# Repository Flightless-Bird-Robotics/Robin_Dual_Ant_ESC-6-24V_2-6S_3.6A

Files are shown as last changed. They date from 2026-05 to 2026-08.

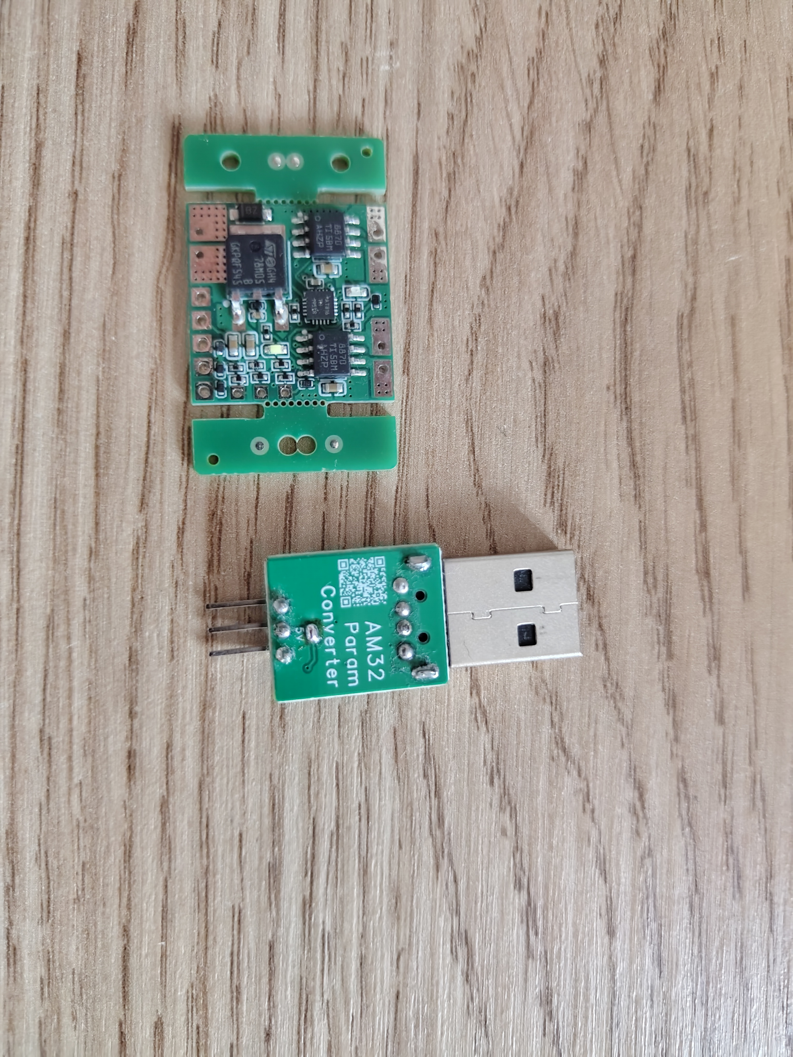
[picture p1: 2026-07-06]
ReadmeMedia/Dual_ESC_6-24V_3.6A_V4_Flash_AM32_3.jpg.jpg

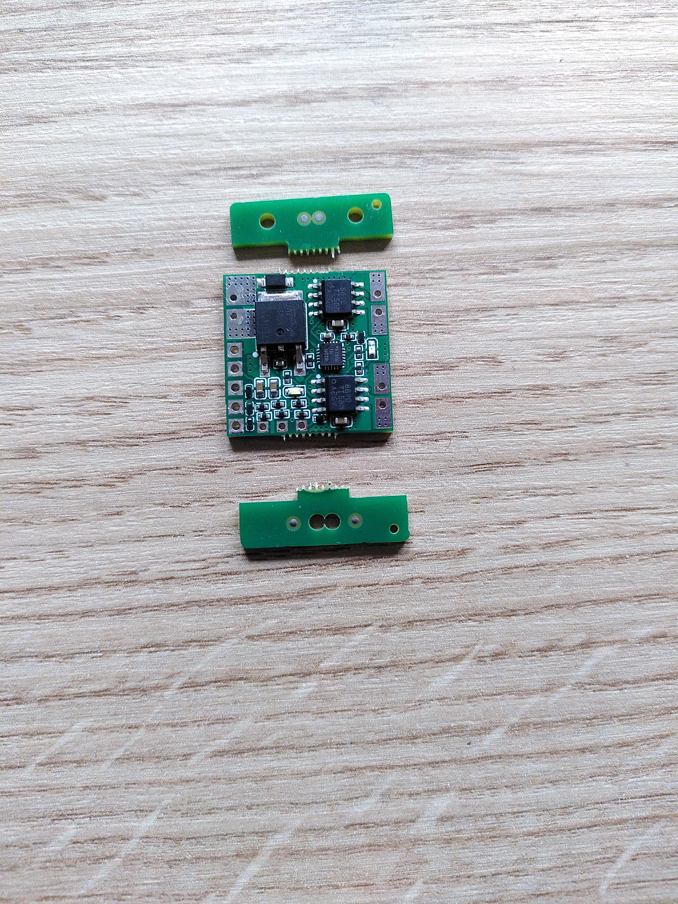
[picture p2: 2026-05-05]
ReadmeMedia/ESC_without_panels.jpg

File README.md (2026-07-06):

# Robin_Dual_Ant_ESC-6-24V_2-6S_3.6A
This ESC is designed for 150g Ant weight combat robots to drive N20 and N10 brushed motors.
It takes standard RC PWM signals as inputs and supports internal mixing and overhead driving.
The ESC is designed to be used with 2-6S, and a maximum current of 3.6A per channel.
The ESC has internal current limiting and thermal shutdown.
The internal BEC can supply up to 100mA for a receiver. An external BEC should be used for voltages over 4S(16.8V).
The PCB without the panels is 22x22mm and weighs 2.3g.

## Wiring section
Dual_ESC_6-24V_3 6A_V3_Wiring_V2
The panels at the top and bottom are just for manufacturing and can be snapped off to reduce the overall size and weight.
ESC_without_panels
The 3 pins at the bottom are for flashing the MCU and are not used in normal operation.
I recomnend to connect the motor 1 to the left drive motor and motor 2 to the right drive motor. The motor 2 polarity should be reversed. This makes mixing later on much easier, and ensures that overhead driving will work correctly. 
You can use standart 2.54mm pitch pins (2x for the battery and motors and 5x for the signal, 5V and GND) to connect the ESC. 
Dual_ESC_6-24V_3 6A_V4_With_Pins
Otherwide you can directly solder it. 

## Programming section
On startup the red LED wil blink once, and the ESC will beep once plus once every cell found when UVLO is enabled.
To program the ESC, power it on and wait for the red LED blink a second time.
The ESC is now in programming mode. 
Any non zero input on the Signal 1 and Signal 2 will end the programming mode. The red LED will be permanently on when in driving mode. 
To enter prgramming mode again, the ESC needs to be power cycled.
In programming mode changing the signal 3 to high (>80) increases the programming counter and the red led blinkes once.
If the right menu number is reached, wait for the red led to blink without any input. The setting has now been activated/deactivated.

| Number  | Function | Default |
| --- | --- | --- |
| 1  | None  |  |
| 2  | No mixing | No mixing |
| 3  | 25% mixing | No mixing |
| 4  | 50% mixing | No mixing |
| 5  | 75% mixing | No mixing |
| 6  | 100% mixing | No mixing |
| 7  | Breaking on/off | Breaking on |
| 8  | Invert channel 1 | Not inverted |
| 9  | Invert channel 2 | Not inverted |
| 10  | Switch channel 1 & 2 | Not switched |
| 11  | Under voltage lockout at 3V per cell  | UVLO off |
| 12  | Wider deadzone on/off | off |
| 13  | reset to default |  |

The UVLO only works when the ESC is connected to a full Lipo on startup, otherwise the ESC cannot detect the number of cells.
On startup the ESC will beep once plus once every cell found.
The motor drivers shut off at 6V, even without UVLO enabled.

## Mixing section
How to set up the ESC for internal mixing with signal 1 for steering and signal 2 for forwards/reverse.
1. Check if motor 1 is the right side drive motor, and the motor is connected with normal polarity.
2. Check if motor 2 is the left side drive motor, and the motor is connected with reversed polarity.
3. Chose on of the 4 mix settings. I recommend to try out every one to get the steering level you are most comfortable with.

## Manufacturing section
### Manufacturing with EasyEDA and JLCPCB
The ESC is designed to be cheaply manufactured in batches as small as 5. (The lowest quantity JLC will manufacture)
The last batch of 5 from JLC cost 22€ including shipping.

The easiest way to get your own ESC manufactured is by importing the .epro file to EasyEDA as a professional projekt.
You can find the file under Hardware/Version/... Now select import document and Library.
Now you need Open the PCB and press order/Order PCB and it will automatically import all the necessary data. Before ordering it will do a design rule check. It should not return any errors and you can continue with the order after it. 
You don't need to change any settings this way except selecting PCB Assembly. You can change the color, or to lead free finish on the PCB if you want, this does not impact the function at all.
Now you can continue to the folliwing steps without needing to change anything and finish your order. Don't forget to appy coupons JLC gives out at checkout.

If you want to order larger quanteties, you can pannelize the PCB in easyEDA under Tools/Panelize. This can be cheaper compared to just ordering a larger number of PCBs. You need to chose "Panel by Customer" when ordering if you do that.

### Manufacturing with gerber files
The other way to get your own PCB manufactured is to upload the Gerber, BOM and CPL file to a manufacturer of choice.
You can find the files under Hardware/Version/...
If you do it with JLC you might need to realign the components. For Other PCB manufacturers everything should work the same, but this was not tested.

### Substituting components for manufacturing
All resistors, TVS Diodes and capacitors are generic. They can be replaced with same spec ones if necessary.
There are generics of the DRV8870 which should work the same, but those were not tested.
The Attiny816 can be replaced with an Attiny1616 if the 816 is not available for whatever reason.
The LDO can be replaced with a same spec LDO if necessary too.

## Flashing section
The microcontroller is flashed using the Arduino IDE and MegaTinyCore from Spencer Konde https://github.com/SpenceKonde/megaTinyCore
To flash the microcontroller a USB to serial adapter is necessary. I used one based on a CP2102M and a schottky diode between RX and TX.
It seems AM32 programmers works as well. I haven't tested this except with the one on the photo. The S pin goes on the UDPI pad.
If you want to try, I recommend to get one where you can deliver 5V to the pins, so you don't need an extra voltage source for programming.
Details to make your own can be found here https://github.com/SpenceKonde/AVR-Guidance/blob/master/UPDI/jtag2updi.md
Once you have installed the MegaTinyCore into the Arduino IDE you need to set the upload settings
Arduino Settings
Now you can connect the UDPI, 5V and GND from the serial adapter to the 3 pins at the bottom.
Dual_ESC_6-24V_3 6A_V3_Flash_Wiring_V2
MCU_Flashing_Photo
Dual_ESC_6-24V_3 6A_V4_Flash_AM32_1
Dual_ESC_6-24V_3 6A_V4_Flash_AM32_3 jpg
Dual_ESC_6-24V_3 6A_V4_Flash_AM32_2 jpg
Now select "Burn bootloader" at the bottom of the "Tools" menue. 
Now you can press upload in the Arduino IDE to upload the code. 
You can check if the microcontroller was flashed sucsecfully by the red led blinking, indicating the programming mode. The ESC can now be used.

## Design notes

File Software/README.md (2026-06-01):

# Software
The software for the ESC is placed here
To uploade it to the ESC you need the Arduino IDE and MegaTinyCore https://github.com/SpenceKonde/megaTinyCore
and a Serial to USB Adapter with an added schottkey diode https://github.com/SpenceKonde/AVR-Guidance/blob/master/UPDI/jtag2updi.md

## The current version is V4
The older version should not be used for harware version 4 and upwards

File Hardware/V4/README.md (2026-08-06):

## Version 4 
This is the fourth hardware version of the dual ant esc
Changes:  -Changed the pinout of the Attiny816 to enagle UVLO
          -Changed the input TVS diode to unidirectional to better protect the input
          -small changes to the silkscreen
          -chnaged some conections for better thermal performance

Added a EasyEDA .epro2 file.
This file is for the version V3 of EasyEDA and should be used for imports in to EasyEDA.

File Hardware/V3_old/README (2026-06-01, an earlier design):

## The UVLO is without function on this Hardware
This is the third hardware version of the dual ant esc
Changes:  -Changed the programing pads to multilayer to make it easier to program with a serial adapter
          -Added through holes to the VIN, GND and motor pads, to give the option to add 2.54mm pitch throughole pins
          -Changed the 5V TVS diodes to unidirectional to better protect the MCU
          -Added pulldown and series resistors on the signal pins to prevent undefined states on the MCU and better protect the MCU
          -Added series Resistor on the UDPI pin to better protect the MCU

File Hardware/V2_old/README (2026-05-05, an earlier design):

**The UVLO is without function on this Hardware**
**This version has multible problems and should not be used.**

This is the second hardware version of this projekt
Changes:  -Cheaper, slightly larger motor drivers were used
          -The pcb size was increased slightly from 20x20mm to 22x22mm

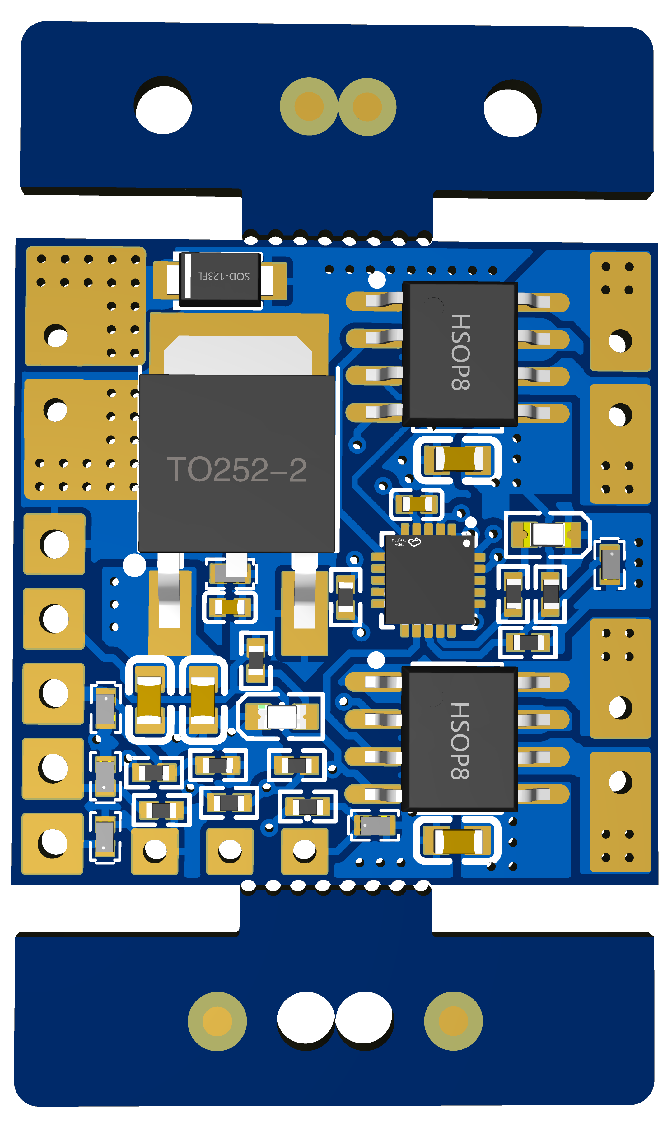
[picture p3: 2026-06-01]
Hardware/V4/Dual_ESC_6-24V_3.6A_V4_Top.png

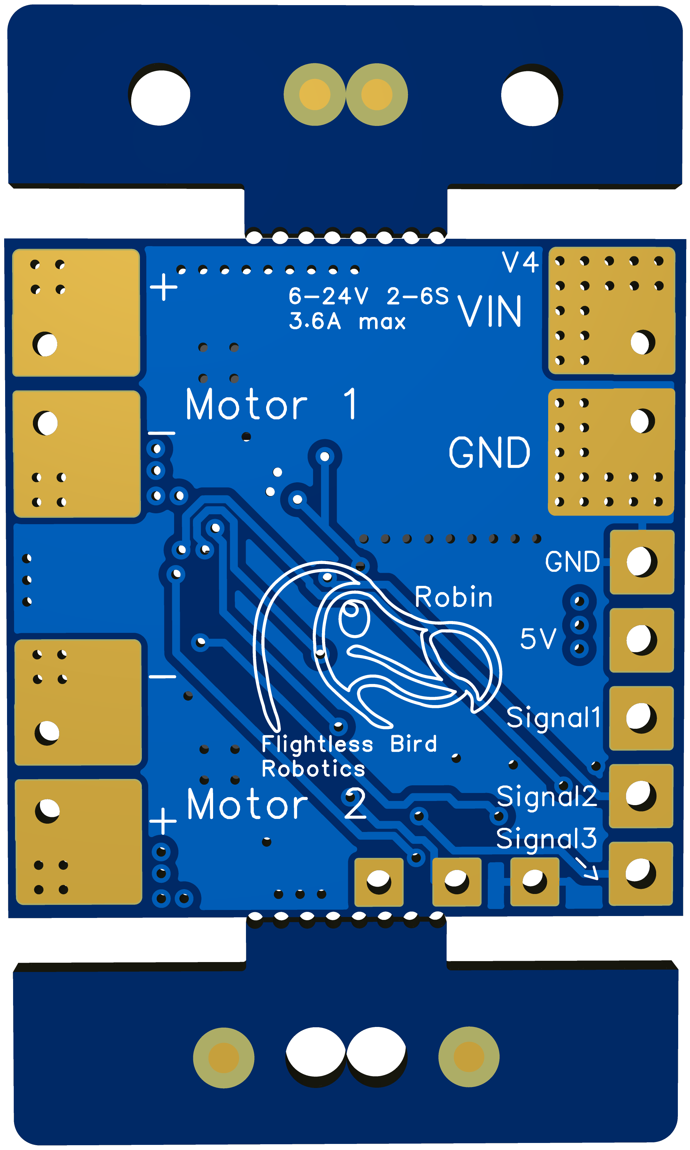
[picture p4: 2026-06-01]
Hardware/V4/Dual_ESC_6-24V_3.6A_V4_Bottom.png

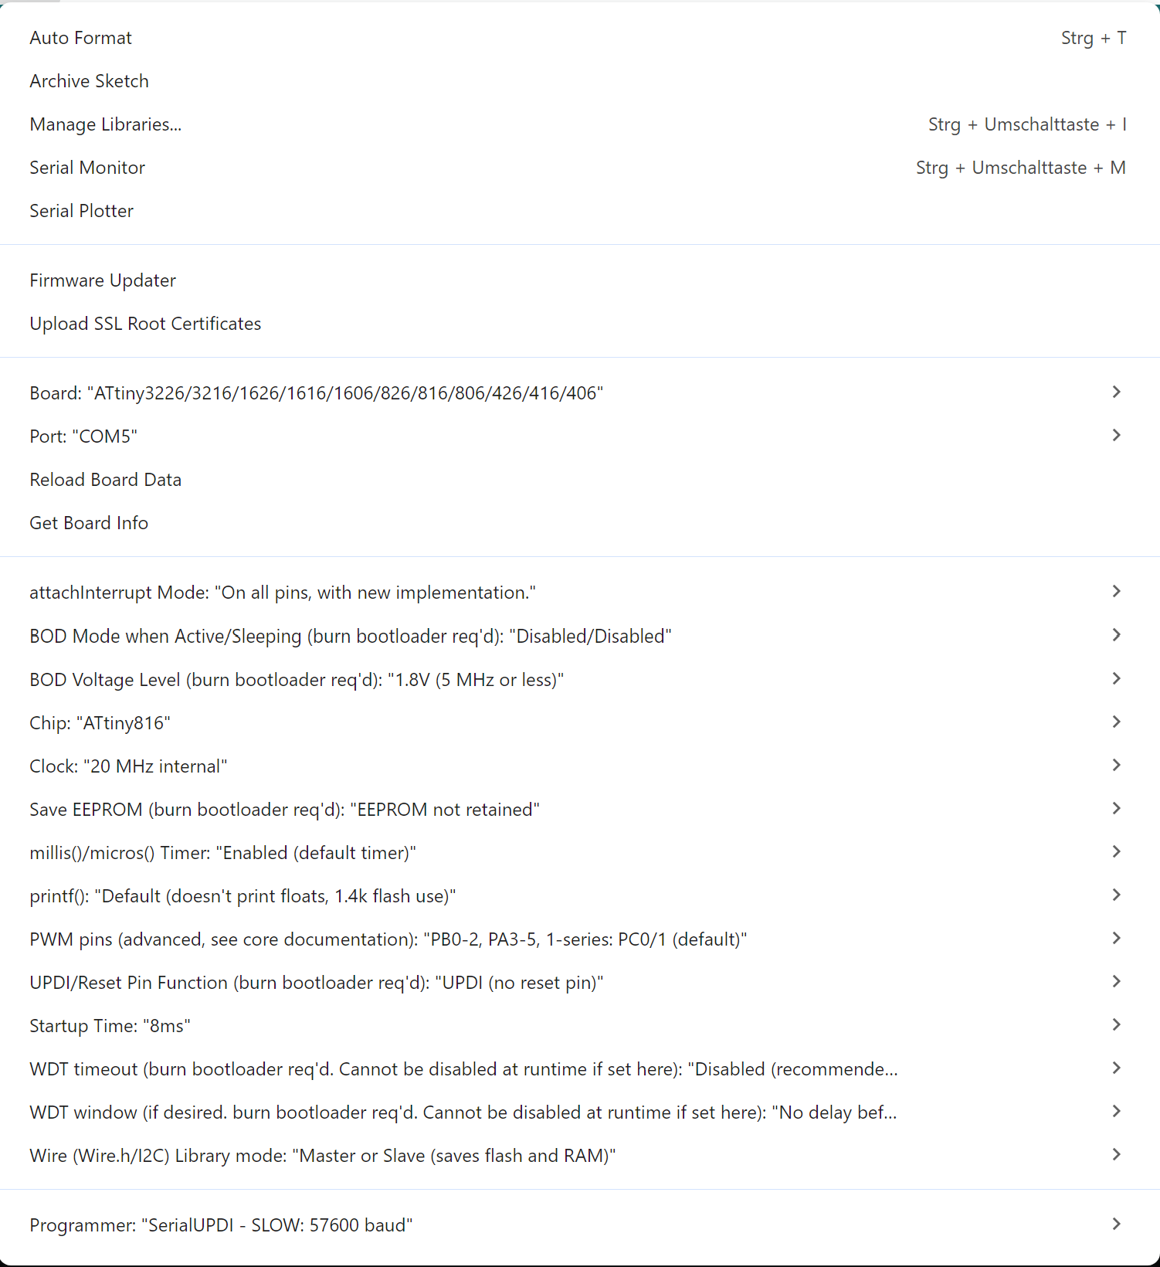
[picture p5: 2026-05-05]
ReadmeMedia/Arduino Settings.png

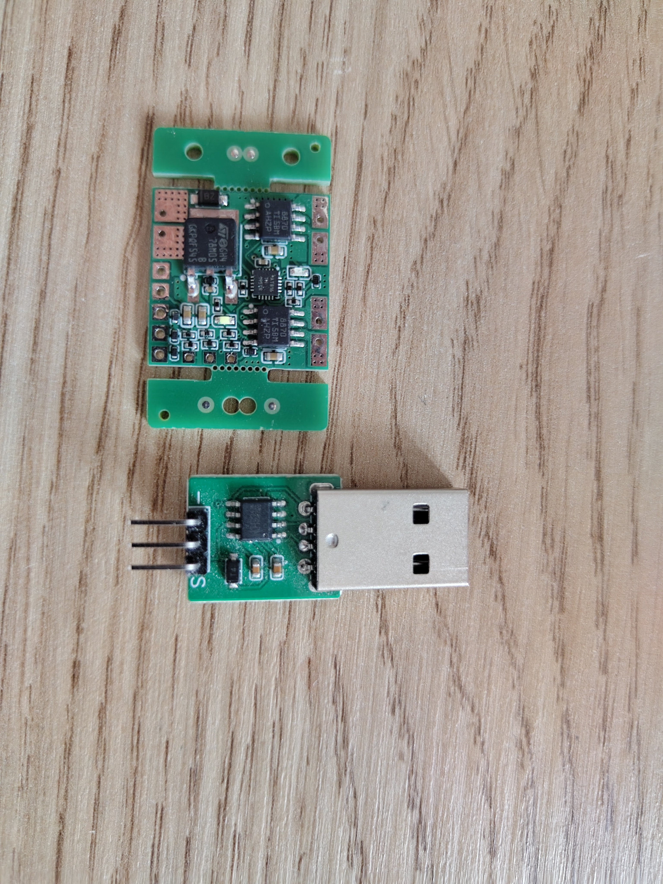
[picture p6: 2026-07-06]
ReadmeMedia/Dual_ESC_6-24V_3.6A_V4_Flash_AM32_2.jpg.jpg

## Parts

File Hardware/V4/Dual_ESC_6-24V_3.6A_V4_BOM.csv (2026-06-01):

No. | Quantity | Comment | Designator | Footprint | Value | Manufacturer Part | Manufacturer | Supplier Part | Supplier
1 | 2 | 1uF | C1,C3 | C0402 | 1uF | CL05A105KA5NQNC | SAMSUNG(三星) | C52923 | LCSC
2 | 4 | 1uF | C2,C4,C5,C6 | C0603 | 1uF | CL10A105KB8NNNC | SAMSUNG(三星) | C15849 | LCSC
3 | 1 | SMF24A | D3 | SOD-123FL_L2.7-W1.8-LS3.8-RD |  | SMF24A | R+O(宏嘉诚) | C19077514 | LCSC
4 | 6 | H5VU10U | D4,D5,D6,D7,D8,D9 | DFN1006-2L-RD |  | H5VU10U | R+O(宏嘉诚) | C22395519 | LCSC
5 | 1 | KT-0603R | LED1RED | LED0603-RD |  | KT-0603R | KENTO | C2286 | LCSC
6 | 1 | KT-0603W | LED2YELLOW | LED0603-R-RD_WHITE |  | KT-0603W | KENTO | C2290 | LCSC
7 | 1 | 100kΩ | R1 | R0402 | 100kΩ | 0402WGF1003TCE | UNI-ROYAL(厚声) | C25741 | LCSC
8 | 4 | 10kΩ | R2,R9,R10,R11 | R0402 | 10kΩ | 0402WGF1002TCE | UNI-ROYAL(厚声) | C25744 | LCSC
9 | 2 | 510Ω | R3,R4 | R0402 | 510Ω | 0402WGF5100TCE | UNI-ROYAL(厚声) | C25123 | LCSC
10 | 4 | 100Ω | R5,R6,R7,R8 | R0402 | 100Ω | 0402WGF1000TCE | UNI-ROYAL(厚声) | C25076 | LCSC
11 | 1 | ATTINY816-MNR | U1 | UQFN-20_L3.0-W3.0-P0.40-BL-EP1.7 |  | ATTINY816-MNR | MICROCHIP(美国微芯) | C2052778 | LCSC
12 | 1 | L78M05ABDT-TR | U2 | TO-252-2_L6.5-W6.1-P4.58-LS10.0-TL |  | L78M05ABDT-TR | ST(意法半导体) | C58069 | LCSC
13 | 2 | DRV8870DDAR | U4,U5 | HSOP-8_L5.0-W4.0-P1.27-LS6.2-BL-EP |  | DRV8870DDAR | TI(德州仪器) | C86590 | LCSC

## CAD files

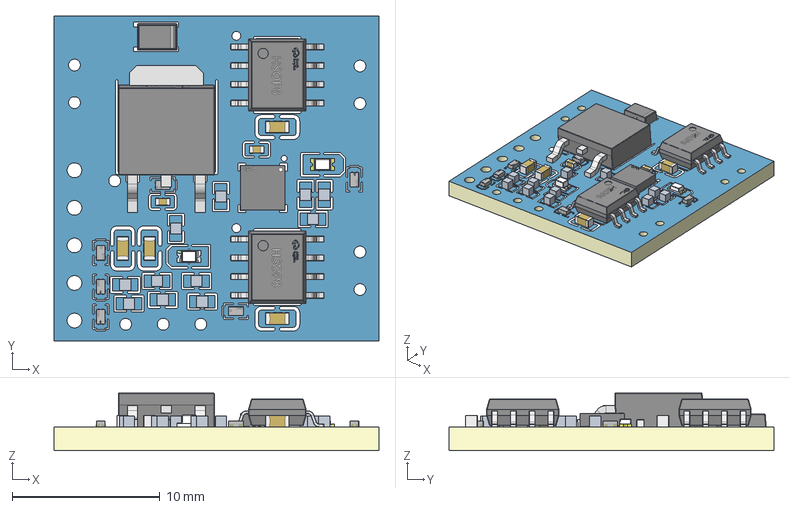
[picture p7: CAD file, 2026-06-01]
Hardware/V4/Dual_ESC_6-24V_3.6A_V4_3D.step
22.0 x 22.0 x 3.91 mm
Board~4Fxs
TopCopper~4Fxs
BottomCopper~4Fxs
TopSilkscreen~4Fxs
BottomSilkscreen~4Fxs
TopFpcStiffener~4Fxs
BottomFpcStiffener~4Fxs
C0402~C0402_L1.0-W0.5-H0.5~4Fxs x 2
R11~R0402~R0402_L1.0-W0.5-H0.4~4Fxs x 11
LED0603-RD~LED0603-RD~4Fxs
C0603~C0603_L1.6-W0.8-H0.8~4Fxs x 4
LED0603-R-RD_WHITE~LED0603-R-RD_WHITE~4Fxs
TO-252-2_L6.5-W6.1-P4.58-LS10.0-TL~TO-252-2_ L6.5-W6.1-H2.3-LS10.0-P4.58~4Fxs
SOD-123FL_L2.7-W1.8-LS3.8-RD~SOD-123FL_L2.8-W1.8-H1.1-LS3.6~4Fxs
UQFN-20_L3.0-W3.0-P0.40-BL-EP1.7~UQFN-20_L3.0-W3.0-P0.40-BL-EP1.7~4Fxs
DFN1006-2L-RD~DFN1006_L1-W0.6-H0.4-2L-RD~4Fxs x 6
HSOP-8_L5.0-W4.0-P1.27-LS6.2-BL-EP~HSOP-8_ L4.9-W3.9-H1.8-LS6.0-P1.27~4Fxs x 2

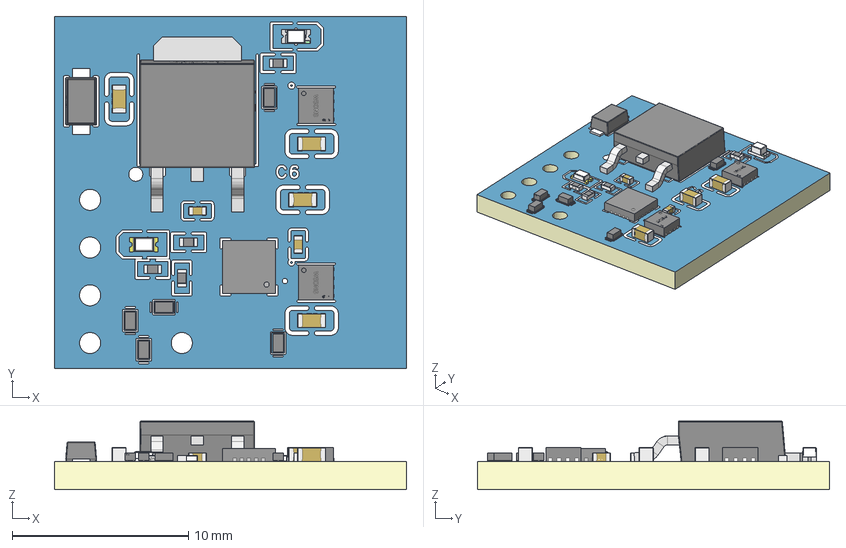
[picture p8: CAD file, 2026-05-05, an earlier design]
Hardware/V1_old/Dual_ESC_6-24V_3.7A_V1_3D.step
20.0 x 20.0 x 3.91 mm
Board~MFEQ
TopCopper~MFEQ
BottomCopper~MFEQ
TopSilkscreen~MFEQ
BottomSilkscreen~MFEQ
TopFpcStiffener~MFEQ
BottomFpcStiffener~MFEQ
C0603~C0603_L1.6-W0.8-H0.8~MFEQ x 4
C0402~C0402_L1.0-W0.5-H0.5~MFEQ x 2
LED0603-RD~LED0603-RD~MFEQ
TO-252-2_L6.5-W6.1-P4.58-LS10.0-TL~TO-252-2_ L6.5-W6.1-H2.3-LS10.0-P4.58~MFEQ
WSON-8_L2.0-W2.0-P0.50-TL-EP~WSON-8_L2.0-W2.0-H0.8-P0.50~MFEQ x 2
R0402~R0402_L1.0-W0.5-H0.4~MFEQ x 4
LED0603-R-RD_WHITE~LED0603-R-RD_WHITE~MFEQ
QFN-20_L3.0-W3.0-P0.40-BL-EP1.7~QFN-20_L3.0-W3.0-P0.40-BL-EP1.7~MFEQ
SOD-123FL_L2.7-W1.8-LS3.8-BI~SOD-123FL_L2.7-W1.8-LS3.8-BI~MFEQ
SOD-882_L1.0-W0.6-BI~WBFBP-03E_L1.0-W0.6-P0.64-BL~MFEQ x 5

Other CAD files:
Hardware/V2_old/Dual_ESC_6-24V_3.6A_V2_3D.step
Hardware/V3/Dual_ESC_6-24V_3.6A_V3_3D.step
Hardware/V3_old/Dual_ESC_6-24V_3.6A_V3_3D.step

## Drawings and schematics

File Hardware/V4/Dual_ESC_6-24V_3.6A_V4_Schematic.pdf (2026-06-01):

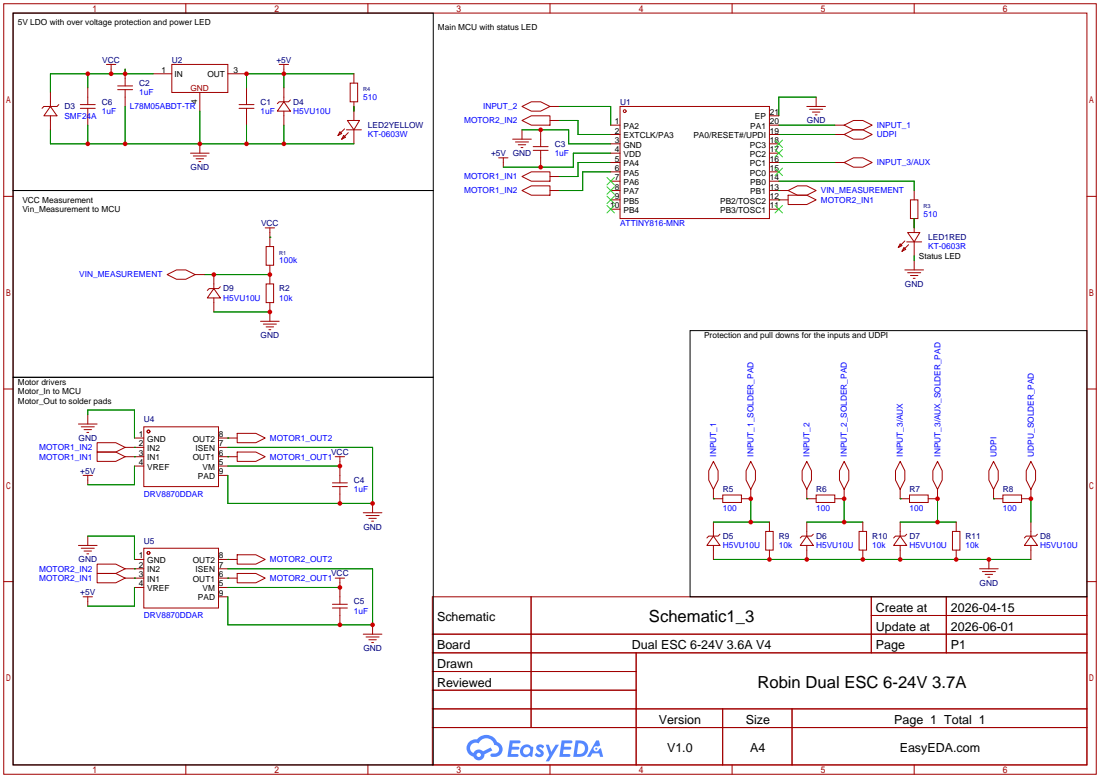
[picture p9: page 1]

5V LDO with over voltage protection and power LED

Main MCU with status LED

Protection and pull downs for the inputs and UDPI

Schematic | Schematic1_3 | Create at | 2026-04-15

Update at | 2026-06-01

Board | Dual ESC 6-24V 3.6A V4 | Page | P1
Drawn | | Robin Dual ESC 6-24V 3.7A
Reviewed

Version | Size | Page 1 Total 1
V1.0 | A4 | EasyEDA.com

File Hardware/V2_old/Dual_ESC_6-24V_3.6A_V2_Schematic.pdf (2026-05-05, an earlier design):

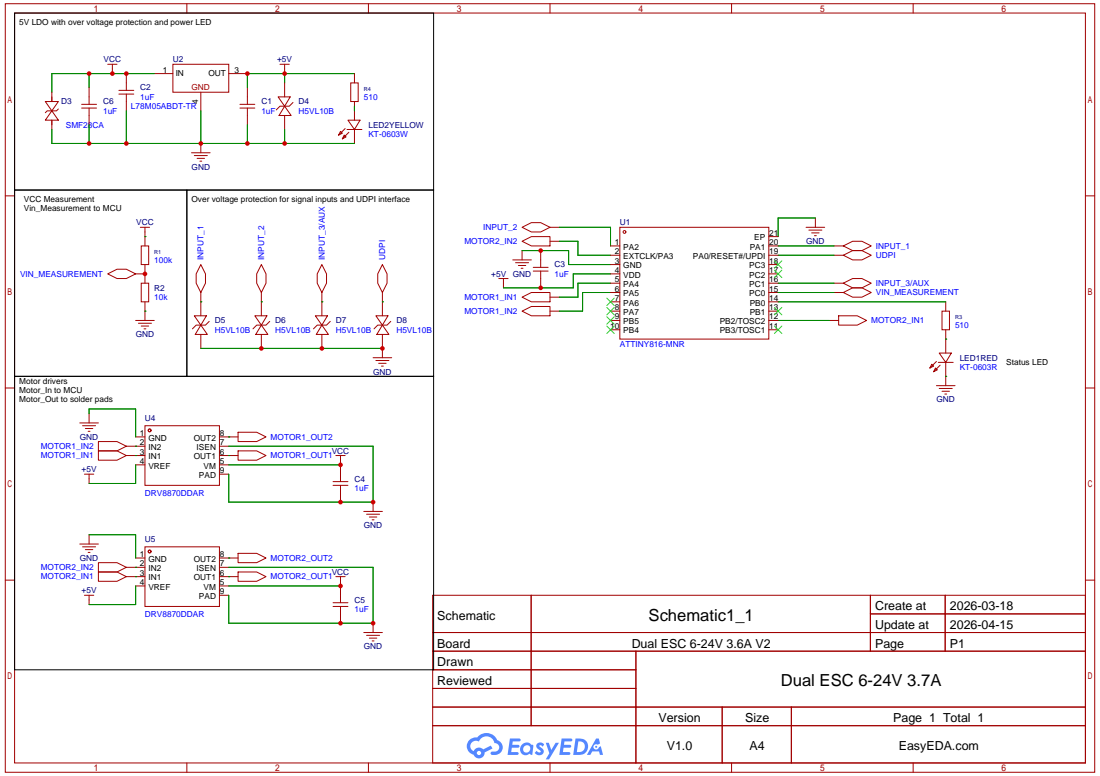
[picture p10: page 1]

5V LDO with over voltage protection and power LED

Over voltage protection for signal inputs and UDPI interface

Schematic | Schematic1_1 | Create at | 2026-03-18

Update at | 2026-04-15

Board | Dual ESC 6-24V 3.6A V2 | Page | P1
Drawn | | Dual ESC 6-24V 3.7A
Reviewed

Version | Size | Page 1 Total 1
V1.0 | A4 | EasyEDA.com

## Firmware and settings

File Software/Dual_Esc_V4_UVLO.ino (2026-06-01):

#include <EEPROM.h>

//Input pins
const int PIN_VIN = 8;

const int PIN_RC_THROTTLE = 14;
const int PIN_RC_STEERING = 15;
const int PIN_RC_AUX      = 11;

//Output pins
const int PIN_LED = 9;

const int PIN_MOTOR_L_A = 0;
const int PIN_MOTOR_L_B = 1;
const int PIN_MOTOR_R_A = 7;
const int PIN_MOTOR_R_B = 16;

const int MAX_PWM = 255;
const int SOUND_PWM_POWER = 60;

const float MIXING_LEVELS[] = {0.0, 0.25, 0.50, 0.75, 1.0};
float currentMix = 0.0;
int mixingIndex = 0;
const int EEPROM_ADDR_MIX = 0;
const int EEPROM_ADDR_BRAKE_EN = 1;
bool brakingEN = false;
const int EEPROM_ADDR_FLIP_CHANNEL_A_B = 2;
bool flipChannel = false;
const int EEPROM_ADDR_INVERT_A = 3;
bool invertA = false;
const int EEPROM_ADDR_INVERT_B = 4;
bool invertB = false;
const int EEPROM_ADDR_UVLO = 5;
bool UVLO = false;
const int EEPROM_ADDR_DEADZONE = 6;
int DEADZONE = 10;

bool inDrive = false;
bool lastAuxStateHigh = false;
bool auxStateChange = false;
bool setupMode = false;
int counter1 = 0;
int counter2 = 0;
int counter3 = 0;
int UVLOcells = 0;
int counterUVLO = 0;
int speedL = 0;
int speedR = 0;

// Variables for interrupts
volatile uint16_t tcb_start_steering = 0;
volatile uint16_t rc_steering_ticks = 0;
volatile uint16_t tcb_start_throttle = 0;
volatile uint16_t rc_throttle_ticks = 0;
volatile uint16_t tcb_start_aux = 0;
volatile uint16_t rc_aux_ticks = 0;
volatile uint16_t throttle_timer = 0;
volatile uint16_t steering_timer = 0;
volatile uint16_t aux_timer = 0;

void setup() {//start setup
  //enable WDT timers
  _PROTECTED_WRITE(WDT.CTRLA,WDT_PERIOD_1KCLK_gc);

//Initialize pins
  pinMode(PIN_MOTOR_L_A, OUTPUT); pinMode(PIN_MOTOR_L_B, OUTPUT);
  pinMode(PIN_MOTOR_R_A, OUTPUT); pinMode(PIN_MOTOR_R_B, OUTPUT);
  pinMode(PIN_RC_STEERING, INPUT); pinMode(PIN_RC_THROTTLE, INPUT); pinMode(PIN_RC_AUX, INPUT);
  pinMode(PIN_LED, OUTPUT);pinMode(PIN_VIN,INPUT);

//Stop motors 
  stopMotors();

//Flash LED
  digitalWrite(PIN_LED, HIGH);                                                                                      

//Reading eeprom settings
  mixingIndex = EEPROM.read(EEPROM_ADDR_MIX);
  if (mixingIndex > 4){mixingIndex = 0;}
  currentMix = MIXING_LEVELS[mixingIndex];
  brakingEN = EEPROM.read(EEPROM_ADDR_BRAKE_EN);
  if(EEPROM.read(EEPROM_ADDR_BRAKE_EN) > 4){brakingEN = 0;}
  flipChannel = EEPROM.read(EEPROM_ADDR_FLIP_CHANNEL_A_B);
  if(EEPROM.read(EEPROM_ADDR_FLIP_CHANNEL_A_B) > 4){flipChannel = 0;}
  invertA = EEPROM.read(EEPROM_ADDR_INVERT_A);
  if (EEPROM.read(EEPROM_ADDR_INVERT_A) > 4){invertA = 0;}
  invertB = EEPROM.read(EEPROM_ADDR_INVERT_B);
  if (EEPROM.read(EEPROM_ADDR_INVERT_B) > 4){invertB = 0;}
  UVLO = EEPROM.read(EEPROM_ADDR_UVLO);   
  if (EEPROM.read(EEPROM_ADDR_UVLO) > 4){UVLO = 0;}
  if (EEPROM.read(EEPROM_ADDR_DEADZONE == 0)){
      DEADZONE = 40;
  }
  else {DEADZONE = 10;}

//Set the ADC voltage reference to 2.5V
  analogReference(2);
  delay(100);
//Set the ADC to 200kHz
  analogClockSpeed(200);
//Reading startup voltages for UVLO with 8 bit resolution and setting the detected number of cells/turning UVLO off
  if(analogReadEnh(PIN_VIN,8) >=  74  && analogReadEnh(PIN_VIN,8) <= 80){//8-8.6V                                        
    UVLOcells = 2;
  }
  else if(analogReadEnh(PIN_VIN,8) >= 111 && analogReadEnh(PIN_VIN,8) <= 120){//12-12.9V
    UVLOcells = 3;
  }
  else if (analogReadEnh(PIN_VIN,8) >= 148 && analogReadEnh(PIN_VIN,8) <= 160){//16-17.2V
    UVLOcells = 4;
  }
  else if (analogReadEnh(PIN_VIN,8) >= 185 && analogReadEnh(PIN_VIN,8) <= 200){//20-21.5V
    UVLOcells = 5;
  }
  else if (analogReadEnh(PIN_VIN,8) >= 222 && analogReadEnh(PIN_VIN,8) <= 240){//24-25.9V
    UVLOcells = 6;
  }
  else{
    UVLO = 0;
  }

       
  //Indicating the UVLO level   
  if (UVLO){                                                                  
    indicateMode(UVLOcells + 1);
  }
  else{
    indicateMode(1);
  }

//Setting registers for Interrrupts
  TCB0.CTRLB = 0;
  TCB0.CTRLA = TCB_CLKSEL_CLKDIV2_gc | TCB_ENABLE_bm;

//Interrupts fot Input reading
  attachInterrupt(digitalPinToInterrupt(PIN_RC_STEERING), isrSteering, CHANGE);
  attachInterrupt(digitalPinToInterrupt(PIN_RC_THROTTLE), isrThrottle, CHANGE);
  attachInterrupt(digitalPinToInterrupt(PIN_RC_AUX), isrAux, CHANGE);


//Flash LED END
  digitalWrite(PIN_LED, LOW);
}//End setup

//Start main loop                                                                 LOOP
void loop() {
    //resetting WDT
  __asm__ __volatile__ ("wdr"::);
  
  uint16_t rawA, rawB, rawAx;


//Disabling interrupts                                                          reading inputs
  noInterrupts();
//Reading the pwm signal values
  rawB = rc_steering_ticks;
  rawA = rc_throttle_ticks;
  rawAx = rc_aux_ticks;
//Enabling interrupts
  interrupts();
//Resizing the input signals to 255
  int inA = ticksToPWM(rawA);
  int inB = ticksToPWM(rawB);
  int AUX = ticksToPWM(rawAx);
  bool auxIsHigh = (AUX > 200);

  //preventing aloss of signal to give any input and setting the inputs to zero
  steering_timer++;
  throttle_timer++;
  aux_timer++;

  //counting up if the UVLO threshold is reached 
  if(UVLOcells != 0 && UVLO) {
    if (analogReadEnh(PIN_VIN,8) <= (UVLOcells * 28)) {
        if (counterUVLO < 12000) {
          counterUVLO++;
          }
    }
    else if(analogReadEnh(PIN_VIN,8) >= (UVLOcells * 29)){
        counterUVLO = 0;
    }
  }
  //Setting motor outputs to 0 if signal lost or UVLO
  if(steering_timer >= 12000 || counterUVLO >= 12000 ){ inB = 0;rc_steering_ticks = 0;}
  if(throttle_timer >= 12000 || counterUVLO >= 12000){ inA = 0;rc_throttle_ticks = 0;}
  if(aux_timer >= 12000){ AUX = 0;rc_aux_ticks = 0;}


  if (!inDrive){                                                              // Settings
      if(auxIsHigh != lastAuxStateHigh){
      auxStateChange = true;
      }
      else{
        auxStateChange = false;
      }
    lastAuxStateHigh = auxIsHigh;
    //Leaving loop/entering driving mode
    if(inA > DEADZONE || inB > DEADZONE || inA < -DEADZONE || inB < -DEADZONE){
      inDrive = true;
    }
    counter1++;
    delay(10);
//enter setup mode
    if (counter1 > 300){
      counter1 = 400;
      if (!setupMode){
      digitalWrite(PIN_LED, true);
      setupMode = true;
      delay(200);
      digitalWrite(PIN_LED, false);
      }
    if (auxIsHigh && auxStateChange){
      counter2++;
      counter3 = 0;
      digitalWrite(PIN_LED,true);
      delay(50);
      digitalWrite(PIN_LED,false);
    }
    if(counter2 > 0){
      counter3++;
      if(counter3 > 300){
        if (counter2 == 1){
          counter2 = 0;
          counter3 = 0;
          digitalWrite(PIN_LED,true);delay(400);digitalWrite(PIN_LED,false);
        }
        else if(counter2 == 2){
          counter2 = 0;
                counter3 = 0;
            currentMix = 0.00;
            EEPROM.update(EEPROM_ADDR_MIX, 0);
            digitalWrite(PIN_LED,true);delay(200);digitalWrite(PIN_LED,false);
        }
          else if (counter2 == 3){
            counter2 = 0;
                  counter3 = 0;
            currentMix = 0.25;
            EEPROM.update(EEPROM_ADDR_MIX, 1);
            digitalWrite(PIN_LED,true);delay(200);digitalWrite(PIN_LED,false);
          }
          else if (counter2 == 4){
            counter2 = 0;
            counter3 = 0;
            currentMix = 0.50;
            EEPROM.update(EEPROM_ADDR_MIX, 2);
            digitalWrite(PIN_LED,true);delay(200);digitalWrite(PIN_LED,false);
          }
          else if (counter2 == 5){
            counter2 = 0;
            counter3 = 0;
            currentMix = 0.75;
            EEPROM.update(EEPROM_ADDR_MIX, 3);
            digitalWrite(PIN_LED,true);delay(200);digitalWrite(PIN_LED,false);
          }
          else if (counter2 == 6){
            counter2 = 0;
            counter3 = 0;
            currentMix = 1.00;
            EEPROM.update(EEPROM_ADDR_MIX, 4);
            digitalWrite(PIN_LED,true);delay(200);digitalWrite(PIN_LED,false);
          }
          else if (counter2 == 7){
            counter2 = 0;
            counter3 = 0;
            if (brakingEN){
              brakingEN = false;
              EEPROM.update(EEPROM_ADDR_BRAKE_EN, 0);
            }
            else {
              brakingEN = true;
              EEPROM.update(EEPROM_ADDR_BRAKE_EN, 1);
            }
            digitalWrite(PIN_LED,true);delay(200);digitalWrite(PIN_LED,false);
          }
          else if (counter2 == 8){
            counter2 = 0;
            counter3 = 0;
            if (invertA){
              invertA = false;
              EEPROM.update(EEPROM_ADDR_INVERT_A, 0);
            } 
            else{
             invertA = true;
              EEPROM.update(EEPROM_ADDR_INVERT_A, 1);
            }
            digitalWrite(PIN_LED,true);delay(200);digitalWrite(PIN_LED,false);
          }
          else if (counter2 == 9){
            counter2 = 0;
            counter3 = 0;
            if (invertB){
              invertB = false;
              EEPROM.update(EEPROM_ADDR_INVERT_B, 0);
            } 
            else{
             invertB = true;
              EEPROM.update(EEPROM_ADDR_INVERT_B, 1);
            }
            digitalWrite(PIN_LED,true);delay(200);digitalWrite(PIN_LED,false);
          }
          else if (counter2 == 10){
            counter2 = 0;
            counter3 = 0;
            if (flipChannel){
              flipChannel = false;
              EEPROM.update(EEPROM_ADDR_FLIP_CHANNEL_A_B, 0);
            } 
            else{
             flipChannel = true;
              EEPROM.update(EEPROM_ADDR_FLIP_CHANNEL_A_B, 1);
            }
            digitalWrite(PIN_LED,true);delay(200);digitalWrite(PIN_LED,false);
          }
          else if (counter2 == 11){
            counter2 = 0;
            counter3 = 0;
            if (UVLO){
              UVLO = false;
              EEPROM.update(EEPROM_ADDR_UVLO, 0);
            } 
            else{
             UVLO = true;
              EEPROM.update(EEPROM_ADDR_UVLO, 1);
            }
            digitalWrite(PIN_LED,true);delay(200);digitalWrite(PIN_LED,false);
          }
          else if (counter2 == 12){
            counter2 = 0;
            counter3 = 0;
            if (DEADZONE == 10){
              DEADZONE = 40;
              EEPROM.update(EEPROM_ADDR_DEADZONE, 1);
            } 
            else{
             DEADZONE = 10;
              EEPROM.update(EEPROM_ADDR_DEADZONE, 0);
            }
            digitalWrite(PIN_LED,true);delay(200);digitalWrite(PIN_LED,false);
          }
          else if (counter2 == 13){
            counter2 = 0;
            counter3 = 0;
            currentMix = 0.00;
            EEPROM.update(EEPROM_ADDR_MIX, 0);
            brakingEN = false;
            EEPROM.update(EEPROM_ADDR_BRAKE_EN, 0);
            invertA = false;
            EEPROM.update(EEPROM_ADDR_INVERT_A, 0);
            invertB = false;
            EEPROM.update(EEPROM_ADDR_INVERT_B, 0);
            flipChannel = false;
            EEPROM.update(EEPROM_ADDR_FLIP_CHANNEL_A_B, 0);
            UVLO = false;
            EEPROM.update(EEPROM_ADDR_UVLO, 0);
            DEADZONE = 10;
            EEPROM.update(EEPROM_ADDR_DEADZONE, 0);
            digitalWrite(PIN_LED,true);delay(200);digitalWrite(PIN_LED,false);
            digitalWrite(PIN_LED,true);delay(200);digitalWrite(PIN_LED,false);
          } 
          else{
            counter2 = 0;
            counter3 = 0;
            digitalWrite(PIN_LED,true);delay(2000);digitalWrite(PIN_LED,false);
          }
      }
      delay(10);
    }
    }
  }
  //Inverting and channel flipping
  if (!invertA){
    inA = -inA;
  }
  if (!invertB){
    inB = -inB;
  }
  if(flipChannel){
    int temp;
    temp = inA;
    inA = inB;
    inB = temp;
  }
  //Overhead Driving
  if(AUX > 200){                                                                                      
    inB = -inB;
  }  
  // mixing
  if(currentMix != 0.00){
    inA =(int)(inA*currentMix);
      speedL = inB +inA;                                                                             
      speedR = inB -inA;
  }
  else{
    speedL = inA;
    speedR = inB;
  }
  speedL = constrain(speedL, -MAX_PWM, MAX_PWM);
  speedR = constrain(speedR, -MAX_PWM, MAX_PWM);
  if (inDrive){                                                                     //Drive                                                                  
    digitalWrite(PIN_LED,true);
    drivePWM(speedL,speedR,brakingEN);
  }
}
 //                                                                                END LOOP

//Plays a number of beeps
void indicateMode(int beeps) {
  for (int i = 0; i < beeps; i++) {
    //resetting WDT
  __asm__ __volatile__ ("wdr"::);
    playTone(2000, 100);
    delay(150);
  }
}

//Play a tone/beep
void playTone(int freq, int durationMs) {
  long periodMicro = 1000000L / freq;
  long halfPeriod = periodMicro / 2;
  long cycles = (long)freq * durationMs / 1000L;

  for (long i = 0; i < cycles; i++) {
    analogWrite(PIN_MOTOR_L_A, SOUND_PWM_POWER); digitalWrite(PIN_MOTOR_L_B, LOW);
    analogWrite(PIN_MOTOR_R_A, SOUND_PWM_POWER); digitalWrite(PIN_MOTOR_R_B, LOW);
    delayMicroseconds(halfPeriod);
    digitalWrite(PIN_MOTOR_L_A, LOW); analogWrite(PIN_MOTOR_L_B, SOUND_PWM_POWER);
    digitalWrite(PIN_MOTOR_R_A, LOW); analogWrite(PIN_MOTOR_R_B, SOUND_PWM_POWER);
    delayMicroseconds(halfPeriod);
  }
  stopMotors();
}

//Converting the input values to -255 to 255
int ticksToPWM(uint16_t ticks) {
  if (ticks < 5000 || ticks > 25000) return 0;
  if (ticks > 14500 && ticks < 15500) return 0;
  long val = (long)ticks - 15000;
  val = map(val, -4000, 4000, -255, 255);
  return constrain(val, -255, 255);
}

void drivePWM(int left, int right,bool brakingEN) {
  setMotor(PIN_MOTOR_L_A, PIN_MOTOR_L_B, left, brakingEN);
  setMotor(PIN_MOTOR_R_A, PIN_MOTOR_R_B, right, brakingEN);
}

void setMotor(int pinA, int pinB, int speed,bool brakingEN) {
  if (speed > DEADZONE) {
    digitalWrite(pinB, LOW); analogWrite(pinA, speed);
  } else if (speed < -DEADZONE) {
    digitalWrite(pinA, LOW); analogWrite(pinB, abs(speed));
  } else {
    if (!brakingEN){
    digitalWrite(pinA, true); digitalWrite(pinB, true);
    }
    else{
    digitalWrite(pinA, LOW); digitalWrite(pinB, LOW);
    }
  }
}

//Stopping motors
void stopMotors() {
  digitalWrite(PIN_MOTOR_L_A, LOW); digitalWrite(PIN_MOTOR_L_B, LOW);
  digitalWrite(PIN_MOTOR_R_A, LOW); digitalWrite(PIN_MOTOR_R_B, LOW);
}

// Interrupt controller
void isrSteering() {
  steering_timer = 0;
  uint16_t now = TCB0.CNT;
  if (digitalRead(PIN_RC_STEERING)) tcb_start_steering = now;
  else rc_steering_ticks = now - tcb_start_steering;
}
//Interrupt controller
void isrThrottle() {
  throttle_timer = 0;
  uint16_t now = TCB0.CNT;
  if (digitalRead(PIN_RC_THROTTLE)) tcb_start_throttle = now;
  else rc_throttle_ticks = now - tcb_start_throttle;
}
//Interrupt controller
void isrAux() {
  aux_timer = 0;
  uint16_t now = TCB0.CNT;
  if (digitalRead(PIN_RC_AUX)) tcb_start_aux = now;
  else rc_aux_ticks = now - tcb_start_aux;
}
